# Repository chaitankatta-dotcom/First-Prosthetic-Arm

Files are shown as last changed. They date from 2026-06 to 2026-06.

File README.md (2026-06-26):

# First-Prosthetic-Arm
This is a very simple prosthetic arms, that can currently do only simple movement by code.

## Overview:
This project is a simple low-cost prosthetic hand designed to demonstrate finger movement using a Raspberry Pi. The hand is mechanically simple, requiring only a small number of moving parts while still being capable of performing basic finger motions.

At its current stage, the fingers are controlled directly through programmed commands. Future versions of the project will incorporate EMG sensors, allowing the hand to respond to muscle signals from the user.

The goal of this project is to create an accessible and easy to build prosthetic hand that can serve as a foundaion for more advanced prosthetic technologies.

## Features:
  Individual finger movment through software conrol
  Raspberry Pi-based control system
  Simple mechanical design with few moving pars
  Modular design for future upgrades
  Expandable to EMG based control

## How it Works:
The prosthetic hand is controlled by by a Raspberry Pi running Python code.

When the program is executed, the Raspberry Pi sends commands to the motors that control the fingers. Different code sequences can be used to create different hand movements such as opening, closing, or gripping motions.

Currently, all movement is controlled through software(micropython code). The hand does not yet interpret muscle signals or user intent automatically.

## How to Use:
  Connect the electronic and motors according to the wiring schemetic picture.
  Upload the provided Python code to the Raspberry Pi for simple movement, or use your own.
  Power on the Raspberry Pi
  Run the control program
  The fingers will move according to the programmed commands,
  Modify the code to create new movement patterns or gestures.

## Why I Made This:
I created this project because I wanted to combine my interest in biology and engineering. Prosthetics are a perfect example of how technology can be used to improve people's lives by restoring lost functionality. As we all are aware that there are many companies who make Prosthetic hands currently. But all of them work based on the user inputs either given by EMG. My goal is to see if we can bring in value to the human kind by adding some Artificial intelligence to the Prosthetic hand which none of the current prosthetic hands in the market have. This is my ultimate goal out of this project.

I was particularly interested in building a project that involved both hardware and programming while also relating to the human body. Designing a prosthetic hand allowed me to explore concepts from biomechanics, robotics, and medicine in a hand on way.

My goal was to create a simple design that demonstrates the fundamentals of a prosthetic tech while leaving room of future improvments such as EMG-based control and more natural movement.

## Overview

This guide explains how to assemble the simple robotic prosthetic hand. The hand uses 3D-printed finger parts, servo motors, screws, rubber bands, jumper wires, and a Raspberry Pi Pico to move the fingers through programmed code.

## Parts Needed

* 3D-printed palm
* 3D-printed finger segments

  * Pinky base, middle, and tip pieces
  * Ring base, middle, and tip pieces
  * Middle finger base, middle, and tip pieces
  * Pointer/index finger base, middle, and tip pieces
  * Thumb base and tip pieces
* 4 SG90 micro servos
* 1 MG996R servo
* Raspberry Pi Pico
* Servo board or mounting plate
* Jumper wires
* Small rubber bands
* M3 screws, nuts, and washers
* Optional M4 screws for larger hinge holes
* Budget soldering kit
* Screwdriver
* Pliers
* Wire Converter
* Boost COnverter
* 3.7V battery
* Optional 3.2 mm drill bit if M3 holes are too tight

## Important Notes Before Assembly

Do not fully tighten the hinge screws at first. The finger joints need to rotate freely. If the screws are too tight, the fingers will become stiff and the servos may not move them properly.

Most screw holes are close to 3 mm in diameter, so M3 screws are the best choice for most joints and mounts. Some larger hinge holes may fit M4 screws, but M3 screws with washers may still work depending on how the parts fit.

Do not power all servos directly from the Raspberry Pi Pico. Servos should use an external 5V power source. The Raspberry Pi Pico and servo power supply must share a common ground.

### Step 1: Prepare the Printed Parts

3D-print parts before assembly.

### Step 2: Assemble Each Finger

Start with one finger at a time.

For each regular finger, connect the pieces in this order:

1. Base finger segment
2. Middle finger segment
3. Tip finger segment

Line up the hinge holes between the parts. Insert an M3 screw through the hinge. Add a washer if needed, then secure it with a nut. Tighten the nut only enough to hold the pieces together while still allowing the joint to rotate.

Repeat this process for the pinky, ring, middle, and pointer/index fingers.

### Step 3: Assemble the Thumb

The thumb has fewer segments than the other fingers. Connect the thumb base piece to the thumb tip piece using the hinge holes.

Insert an M3 screw through the hinge and secure it with a nut. Keep the joint loose enough so the thumb can rotate smoothly.

### Step 4: Attach the Fingers to the Palm

Place each assembled finger into its correct position on the palm:

* Pinky on the outside edge
* Ring finger next to the pinky
* Middle finger in the center
* Pointer/index finger next to the thumb side
* Thumb on the side of the palm

Line up the base hinge holes of each finger with the matching holes on the palm. Insert screws through the hinge points and secure them with nuts.

### Step 5: Mount the Servos

Mount the SG90 servos into the servo slots or servo board area. These servos control the smaller finger movements.

Use small screws to secure the servos in place. If the servo mounting holes are around 3 mm, use M3 screws. If the holes are smaller, use the screws that came with the servos.

Mount the MG996R servo in the larger servo position. This servo is stronger and should be used for a larger movement, such as wrist, palm, or thumb motion depending on your design.

Make sure all servo horns can rotate without hitting the palm or finger parts.

### Step 6: Connect the Rubber Bands

Attach small rubber bands to the fingers so they help return the fingers to their open position.

### Step 7: Connect Servos to Fingers

Connect each servo horn to its matching finger using string, wire, or linkage depending on your design.

Before attaching the servo horn permanently, center the servo using code. This prevents the finger from starting in the wrong position.

### Step 8: Wire the Electronics

Each servo has three wires:

* Red wire: 5V power
* Brown or black wire: Ground
* Orange, yellow, or white wire: Signal

Suggested Raspberry Pi Pico signal pins:

* SG90 servo 1: GP11
* SG90 servo 2: GP12
* SG90 servo 3: GP13
* SG90 servo 4: GP14
* MG996R servo: GP15

Connect all servo ground wires to the external power supply ground. Also connect the Raspberry Pi Pico ground to the same ground. This is called a common ground.

Use an external 5V power source for the servos. Do not power all the servos from the Pico’s 3.3V pin. Use the Boost converter with battery to acheive 5V.

### Step 9: Upload Test Code

Upload simple servo test code to the Raspberry Pi Pico.

Test one servo at a time first. Make sure each servo moves correctly before testing all fingers together.

## Credits

Blender, Onshape and finally Thank you so much to all my Friends & Mentors

## Pictures




## BOM

## Bill of Materials (BOM)

| Item | Description | Quantity | Unit Cost (USD) | Total Cost (USD) | Link |
|---|---|---:|---:|---:|---|
| SG90 Servo | SG90 9g micro servo motor | 4 | $2.75 | $10.98 | https://www.amazon.com/Micro-Miuzei-Servos-Arduino-Airplane/dp/B0FGQ432JP |
| MG996R Servo | MG996R metal gear high torque servo | 1 | $4.99 | $4.99 | https://www.waveshare.com/mg996r-servo.htm |
| Jumper Wires | Raspberry Pi/Arduino jumper wire pack | 1 | $5.99 | $5.99 | https://vilros.com/products/jumper-wires |
| Raspberry Pi Pico | Raspberry Pi Pico microcontroller board | 1 | $3.99 | $3.99 | https://www.microcenter.com/product/661033/raspberry-pi-pico-microcontroller-development-board |
| Budget Soldering Kit | Basic soldering iron kit for connecting wires/electronics | 1 | $10.99 | $10.99 | https://www.walmart.com/ip/Soldering-Iron-Kit-Electric-60W-110V-Adjustable-Temperature-Soldering-Gun-Welding-Tools-5pcs-Replacement-Tips-and-Solder-Wire-Tube-Basic/5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 |
| Boost Converter | Boost converter for stepping battery voltage up to 5V for powering electronics/servos | 1 | $7.21 | $7.21 | https://www.aliexpress.us/item/3256806768533807.html |
| Battery | Battery power source for the prosthetic hand electronics | 1 | $12.14 | $12.14 | https://www.aliexpress.us/item/3256809973651639.html |
| Wire Converter | Wire converter/adapter for power connections | 1 | $2.79 | $2.79 | https://www.aliexpress.us/item/3256806148630793.html |
| Small Rubber Bands | Small rubber bands for finger return tension or elastic movement | 1 | $4.99 | $4.99 | https://www.amazon.com/s?k=small+rubber+bands |
| M3 Screw Assortment Kit | M3 screws/bolts with nuts and washers for most finger and palm holes | 1 | $8.99 | $8.99 | https://www.amazon.com/s?k=M3+screw+assortment+kit+nuts+washers |
| M4 Screws | Optional M4 screws for larger hinge holes around 4 mm diameter | 1 | $6.99 | $6.99 | https://www.amazon.com/s?k=M4+screws+nuts+washers |
| **TOTAL** |  |  |  | **$80.05** |  |

## Zine

Low Cost Prosthetic Hand (4)

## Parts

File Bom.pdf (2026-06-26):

# Super Duper Low Cost Prosthetic Hand

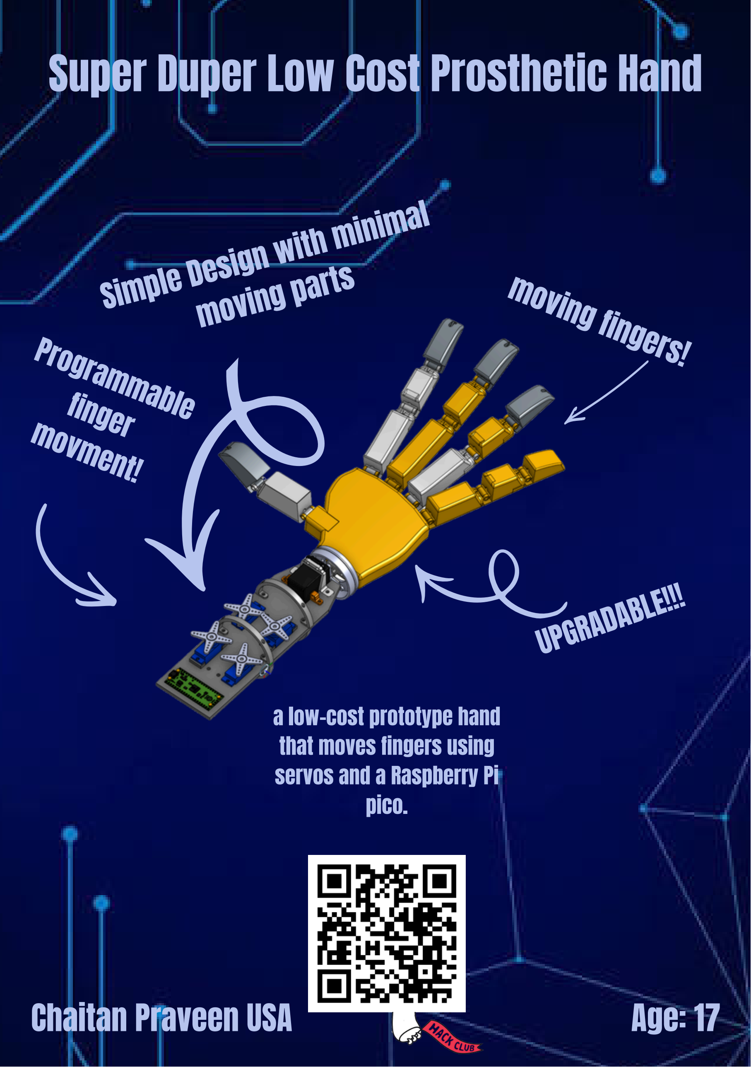
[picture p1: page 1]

a low-cost prototype hand
that moves fingers using
servos and a Raspberry Pi
pico.

## moving fingers!

## Simple Design with minimal moving parts

## Pro

f

g
in

## rammable

m

## ger ovment!

## UPGRADABLE!!!

Chaitan Praveen USA | Age: 17

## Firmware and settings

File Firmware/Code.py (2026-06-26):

import machine
import utime

servo_pins = [11, 12, 13, 14, 15]

servos = []
for pin in servo_pins:
    pwn_obj = machinePWN(machine.Pin(pin))
    pwn_obh.freq(50)
    servos.append(pwn_obi)

def move_all_servos(angles):
    for i in range(5):
        angle = max(0, min(180, angles[i]))
        pulse_width_us = 500 + (angle / 180.0) * 1900
        duty_u16 = int((pulse_width_us / 20000) * 65535)
        servos[i].duty_u16(duty_u16)
        
try:
    while True:
        print("Step 1: All at 0")
        move_all_servos([0, 0, 0, 0, 0])
        utime.sleep(1.0)
        
        print("Step 2: 4 servos to 45 & 5th to 90")
        move_all_servos([45, 45, 45, 45, 90])
        utime.sleep(1.0)
        
        print("step 3: 4 servos to 90 & 5th to 180")
        move_all_servos([90, 90, 90, 90, 180])
        utime.sleep(1.0)
        
        print("step 4: 4 servos to 135 & 5th stays at 180")
        move_all_servos([135, 135, 135, 135, 180])
        utime.sleep(1.0)
        
        print("step 5: 4 servos to 180 & 5th stays at 180")
        move_all_servos([180, 180, 180, 180, 180])
        utime.sleep(1.0)
        
except KeyboardInterrupt:
    for pwm in servos:
        pwn.deinit()
        print("done bud")

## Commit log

2026-06-19 Create CAD files
2026-06-19 Add BOM file with components and costs
2026-06-19 Add link to Backup Assembly in CAD files
2026-06-19 Update BOM with new items and total cost
2026-06-19 Update M3 Screw Assortment Kit URL in BOM
2026-06-19 Update BOM
2026-06-20 Add BOM section to README
    Added a Bill of Materials (BOM) section with item details.
2026-06-20 Create BOM V2
2026-06-20 Fix BOM total line formatting
2026-06-20 Rename Untitled spreadsheet - BOM (4).csv to BOM
2026-06-22 Update print statement from 'Hello' to 'Goodbye'
2026-06-22 Rename wiring.kicad_pro to Wiring/wiring files
2026-06-22 Add more wiring files
2026-06-22 Update BOM file
2026-06-22 Refine assembly instructions in README.md
    Removed unnecessary bullet points and streamlined instructions for assembling the robotic hand.
2026-06-22 Revise BOM with new items and updated total cost
    Updated BOM section with new items and corrected total cost.
2026-06-22 Add link to BOM spreadsheet in README
    Updated total cost to include a link to the BOM spreadsheet.
2026-06-22 Update BOM section to markdown format
2026-06-25 Cad file change
2026-06-25 wiring updated
    [wiring.kicad_sch]
2026-06-25 Update component list and total cost in README
    Added new components including Boost Converter, Battery, and Wire Converter with updated total cost.
2026-06-26 Update assembly instructions and power source details
    Clarified instructions on 3D-printing parts and powering servos.
